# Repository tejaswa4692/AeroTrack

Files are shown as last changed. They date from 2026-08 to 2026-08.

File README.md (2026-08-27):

# Aero Track

Why should directional antennas be handicapped by the fact theyre directional, i made a rig (can be used with any directional antennas) that can be used to track a target anywhere on the earth
It will do all the math to point the antennas towards a GPS coordinate, It does have its own GPS but if you dont want to use it its totally upto you its just there for quality of life and ease of use at the field.
This project was developed to aid my Long range endurance UAV project that i also submitted for stardance and got funding from, This will help me make a groundstation that can have insane range without sacrificing directionality

Where has my love for yagi antennas brought me 😍😍✌️✌️

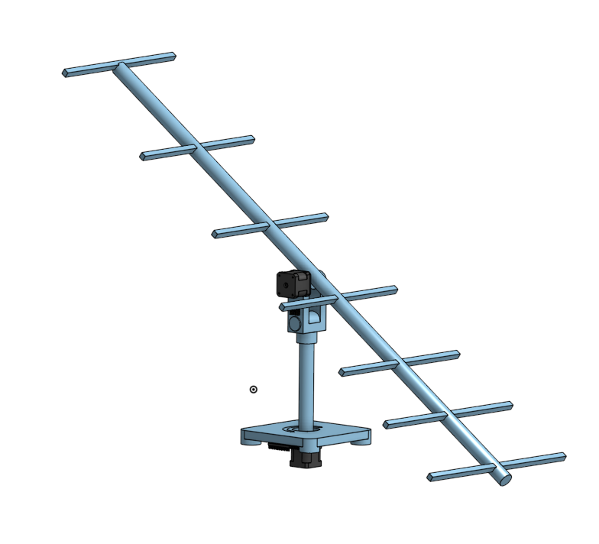
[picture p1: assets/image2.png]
Yagi Rig

___

I will be implementing full support with the Mavlink protocol so you can either directly plug ur mavlink telemetry reciever in or route the data through a laptop

## System Architecture

It uses two stepper motors with encoders for pitch and yaw 

```
base.rotation.y = atan2(local_target.x, local_target.z)
antenna.rotation.x = -atan2(local_target.y, Vector2(local_target.x, local_target.z).length()) + deg_to_rad(90)
```
(lines taken straight out of my game code btw it does work irl too)

These two formulas will be used to point the yagi towards the location i want it to point to, which will ofcourse be GPS coords in this case

I have tested this in my game which i ALSO submitted for stardance and got a superstar on 

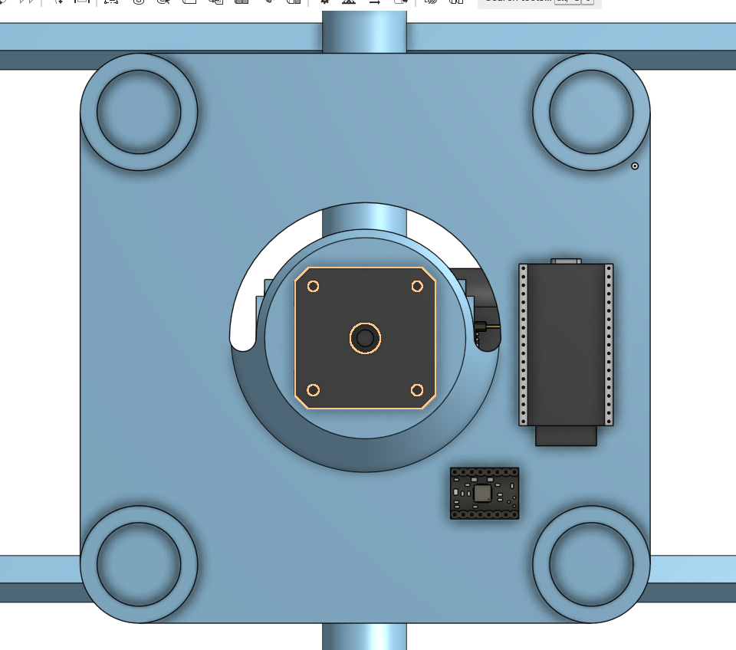
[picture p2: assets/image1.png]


### Electronics

[bom.csv](./bom.csv)

### Antenna

Yagi is a highly directional antenna which has insane range for anything thats directly infront of it, its used a LOT in TV communication and for groundstations where they know the position of the gs and they directly point it to that point
Hugely used in aerospace 

### 433 MHz Yagi

### 433 MHz Yagi — Element Dimensions

| Element | Length (mm) | Distance from Reflector (mm) |
|---|---|---|
| Reflector | 346 | 0 |
| Driven (dipole) | 329 | 138 |
| Director 1 | 311 | 276 |
| Director 2 | 308 | 486 |
| Director 3 | 305 | 767 |
| Director 4 | 303 | 1024 |
| Director 5 | 301 | 1257 |

## Wiring

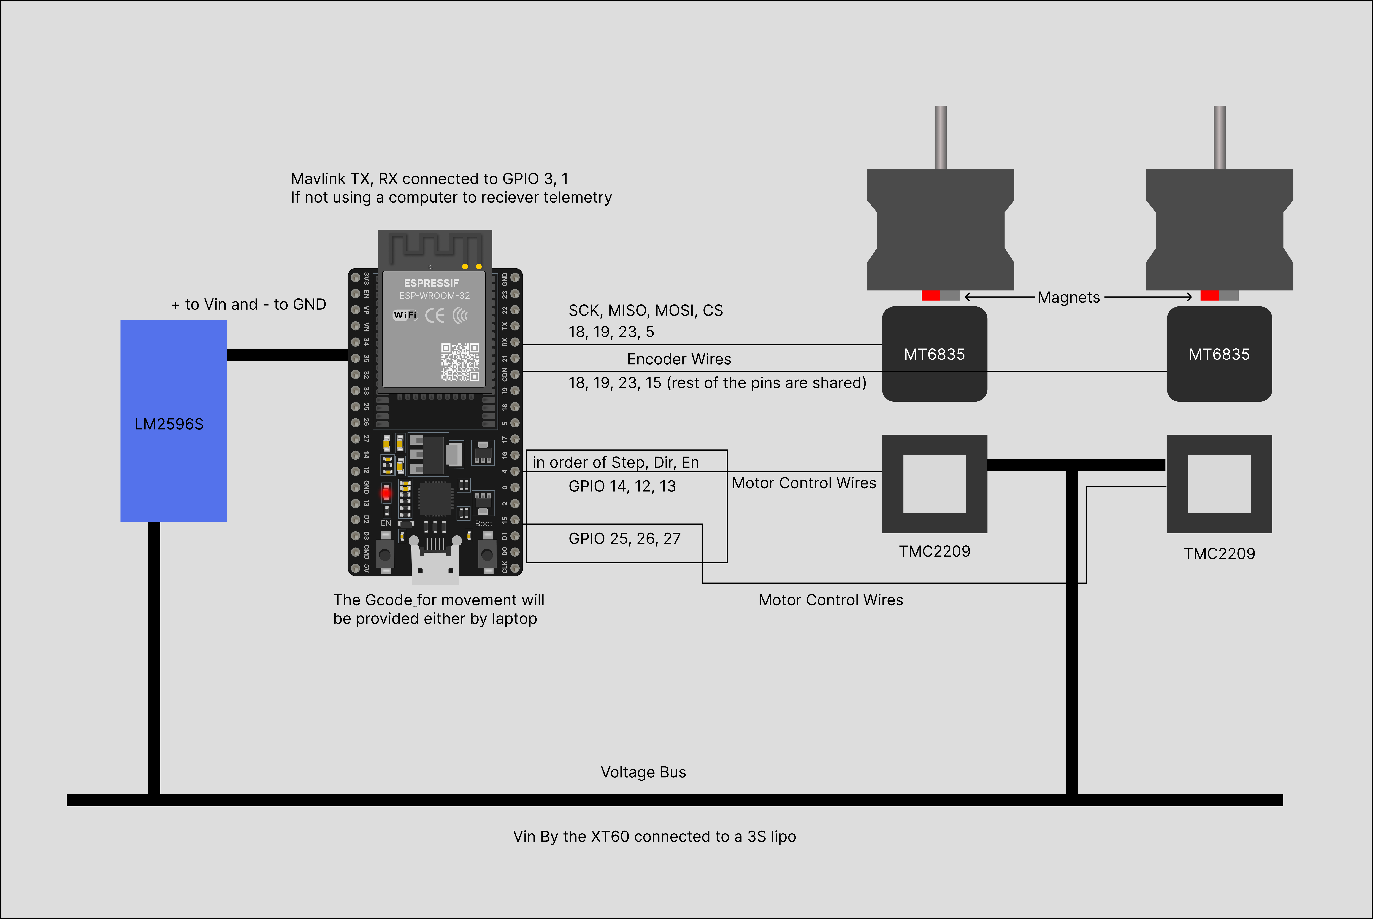
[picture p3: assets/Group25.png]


### Pin Connections

| Signal | ESP32 Pin | Connects To |
|---|---|---|
| Yaw Step | GPIO 25 | Stepper Driver 1 (STEP) |
| Yaw Dir | GPIO 26 | Stepper Driver 1 (DIR) |
| Yaw Enable | GPIO 27 | Stepper Driver 1 (EN) |
| Pitch Step | GPIO 14 | Stepper Driver 2 (STEP) |
| Pitch Dir | GPIO 12 | Stepper Driver 2 (DIR) |
| Pitch Enable | GPIO 13 | Stepper Driver 2 (EN) |
| Yaw Encoder SCK | GPIO 18 | MT6835 #1 (SPI SCK) |
| Yaw Encoder MISO | GPIO 19 | MT6835 #1 (SPI MISO) |
| Yaw Encoder MOSI | GPIO 23 | MT6835 #1 (SPI MOSI) |
| Yaw Encoder CS | GPIO 5 | MT6835 #1 (SPI CS) |
| Pitch Encoder CS | GPIO 15 | MT6835 #2 (SPI CS, shares SCK/MISO/MOSI) |
| GPS RX | GPIO 16 | GPS Module TX |
| GPS TX | GPIO 17 | GPS Module RX |
| MAVLink RX | GPIO 3 (RX0) | Telemetry Radio TX |
| MAVLink TX | GPIO 1 (TX0) | Telemetry Radio RX |
| Motor Power | VMOT | 12V Supply |
| Logic Power | 3.3V | ESP32 / Encoders |

Note: The encoder pins might be different for different encoders

## Design process
### The 433 Dipole 
Coming soon... (i dont wanna provide any false instructions)
### Firmware
Coming soon...
### Screws
insert all the provided heatset inserts before moving on to assembling the rig, the longer inserts go in the baseplate and keep in mind to leave space at top so that the screws can sit flush
the smaller 3mm inserts are tapped on the yaw arm
### Assembling the rig
1. Start by taking your boom and place the first reflector element at the end, cut the reflector to match the size given in the chart above (keep in mind it should be symmetric)
2. Place the dipole you just created 13.8cm ahead of it
3. Match the table for however many directors you want (the more the more directional it becoems)
4. Put the YagiBoomMount.step under the CG of the yagi antenna
5. Take out your 6000 bearings and slide them in the yaw arm
6. position the yagi antenna boom mounts notch inside the bearing and side your nema 17 from the side screwing it in the place
7. Slide down your 2.5cm stick under the yaw arm and superglue it in place
8. Use a lathe or drill a hole to put a 5mm shaft inside the 2.5cm shaft so that it sticks out
9. Screw your Nema17 under the baseplate before you begin the assembly
10. Slide the 6005 bearings in the base plate then follow it by adding the yawarm in, use the aluminum coupling to screw both in place
11. Rougly connect everything according to the wiring diagram to the ESP32 and mount the GPS as away from the yagi on baseplate facing up

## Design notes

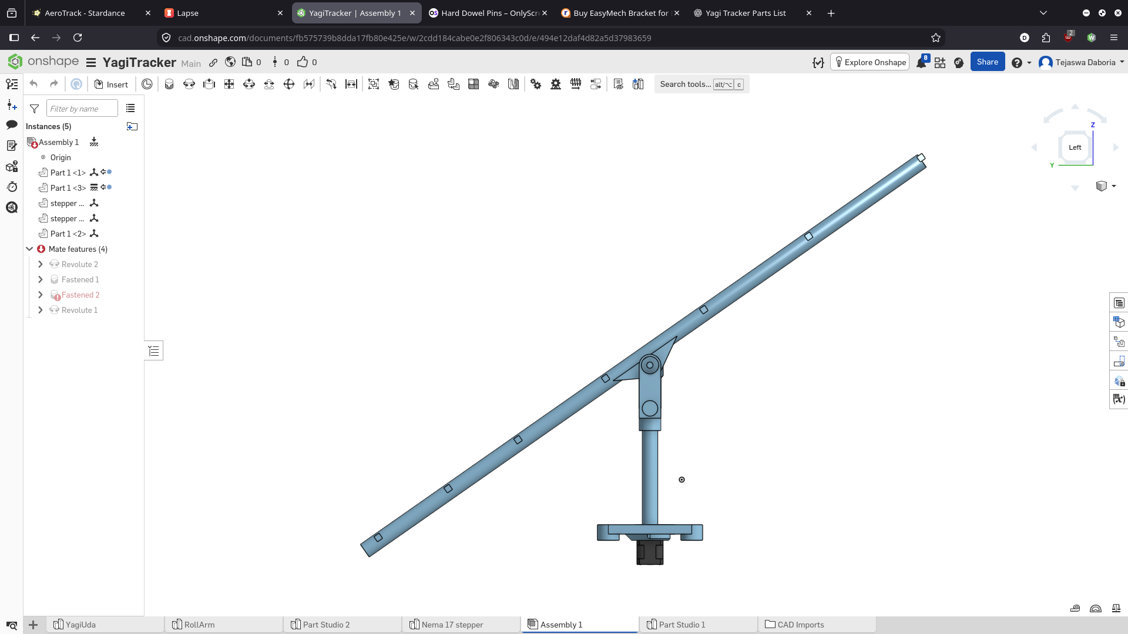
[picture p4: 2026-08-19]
assets/Screenshot_20260819_000037.png

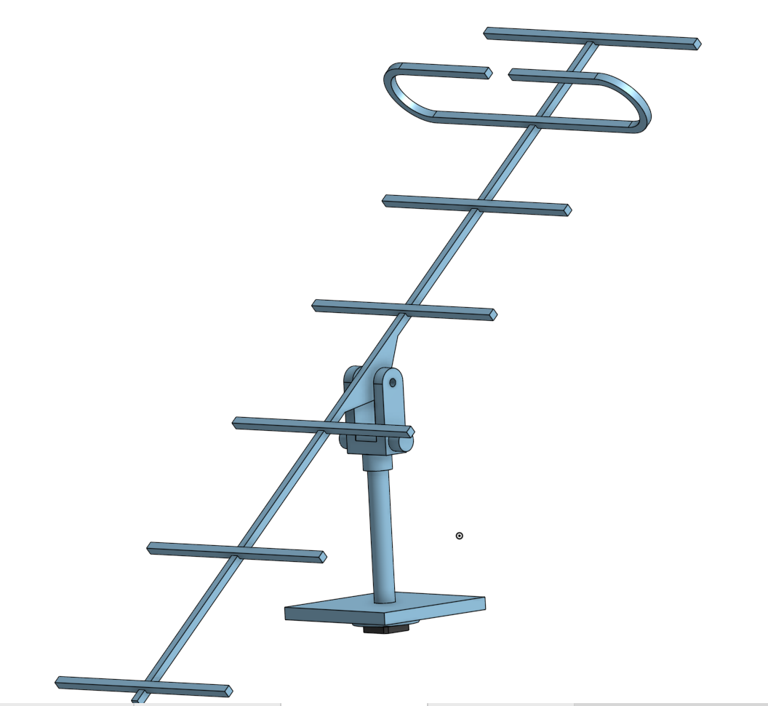
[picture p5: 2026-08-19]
assets/Screenshot_20260816_004432.png

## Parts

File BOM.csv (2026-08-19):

Item Name | Qty | Price (total) (USD) | Item link | Notes
3 ft wood dowels | 1 | $3.00 | https://www.amazon.in/Global-Hanging-Macram%C3%A9-Tapestries-Projects/dp/B0H7MLPWMG?th=1 | Wood dowles used to make the boom for yagi antenna (not using cf cuz conductive)
M3 x 12 screw | 6 | $0.21 | https://onlyscrews.in/products/hex-allen-socket-head-m3-x-12-screw-pack-of-20?variant=48590915567929 | M3 x 12 for mounting the NEMA 17 to base plate
M3 x 3mm threaded inserts | 6 | $0.28 | https://onlyscrews.in/products/m3-x-3mm-brass-threaded-inserts?variant=49729062273337 | For the rotating arm
M3 x 8 threaded inserts | 6 | $0.19 | https://onlyscrews.in/products/m3-x-8mm-brass-threaded-inserts?variant=49423134327097 | For the base plate
6000Z bearing | 2 | $0.38 | https://onlyscrews.in/products/6000-zz-deep-groove-ball-bearing-10x26x8?variant=50974148362553 | THis bearing will be for the arm (yaw)
6005Z bearing | 2 | $0.90 | https://onlyscrews.in/products/6005-zz-deep-groove-ball-bearing-25x47x12?variant=50975888376121 | This bearing will be for the base plate (pitch)
M3 x 6 screws | 6 | $0.11 | https://onlyscrews.in/products/m3-x-6mm-hex-allen-socket-head-high-tensile12-9-black-oxide-screw-dia-3mm-length-6mm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 | Mounting screws for NEMA 17
ESP32-32D | 1 | $8.55 | https://robu.in/product/smartelex-esp-wroom-32-wifi-bluetooth-networking-development-board-1-pcs/ | ESP with enough pins to power the project
TMC2209 | 2 | $11.88 | https://robu.in/product/tmc2209-stepper-motor-driver/ | Stepper motor driver w high accuracy
MT6835 | 2 | $15.22 | https://robu.in/product/mt6835-magnetic-encoder-module-pwm-spi-brushless-motor-21bit-encoder-with-magnet-to-replace-as5048-ab-16384/ | Best quality stepper encoder to find shaft angle
LM2596S | 2 | $0.92 | https://robu.in/product/lm2596s-dc-dc-buck-converter-power-supply/ | Buck convertor to power the ESP (might need to use smt else but this is js for the prototype)
NEO-6M GPS | 1 | $3.00 | https://robu.in/product/neo-6m-gps-module-with-eprom-normal-quality/ | Cheap GPS works just fine to find the position of antenna
NEMA17 4.2 kg | 2 | $14.62 | https://robu.in/product/nema17-40mm-1-2a-unipolar-stepper-motor-w-1m-cable/ | 4.2Kg Nema17 has more than enoguh power to move the entire earth on its own
Aluminum NEMA17 Shaft Coupling | 1 | $1.19 | https://robu.in/product/easymech-aluminium-nema17-shaft-coupling-5mm-x-8mm/ | This holds the wood dowel of the arm
NEMA 17 Stepper Motor Bend Sturdy Mount | 1 | $2.11 | https://robu.in/product/easymech-bracket-for-nema-17-stepper-motor/ | If incase the arm mounting bracket is too flimsy for the nema 17 chonky boy i will use this instead
XT60 | 1 | $0.31 | https://robu.in/product/xt60h-connector-with-housing-male/ | To power the project im using a 3s lipo
Wire | 1 | $0.20 | https://robu.in/product/high-quality-ultra-flexible-22awg-silicone-wire-1000m-black/ | Wire to spread the electricity
F-F jumpers | 3 | $1.38 | https://robu.in/product/male-to-female-jumper-wires-40pcs-20cm/ | For the initial prototyping stage i will be soldering them manually later
Tire spokes | 20 | $7.00 | Local Shop | For the yagi director
Single core copper wire | 2 | $0.35 | https://robu.in/product/26awg-single-core-teflon-wire-red/ | Driven element single cored copper wire enough for multiple types of antennas
RP SMA 1m Male-Male Cable | 1 | $7.11 | https://www.amazon.in/gp/product/B0GZLPBMM2?smid=AID930I70H9OP&th=1 | 1 m long RP SMA male - male coax to wire the yagi
RP sma 5 cm female cable | 1 | $0.82 | https://robu.in/product/5cm-ipex-1-to-rp-sma-female-connector-cable-11mm-rg1-13/ | a small female rp sma connector so i dont ruin the coax cable when making the yagi
OnlyScrews delivery charge | 1 | $1.10 | OnlyScrews delivery charge | OnlyScrews delivery charge
Total Price (USD):
 |  | $80.83

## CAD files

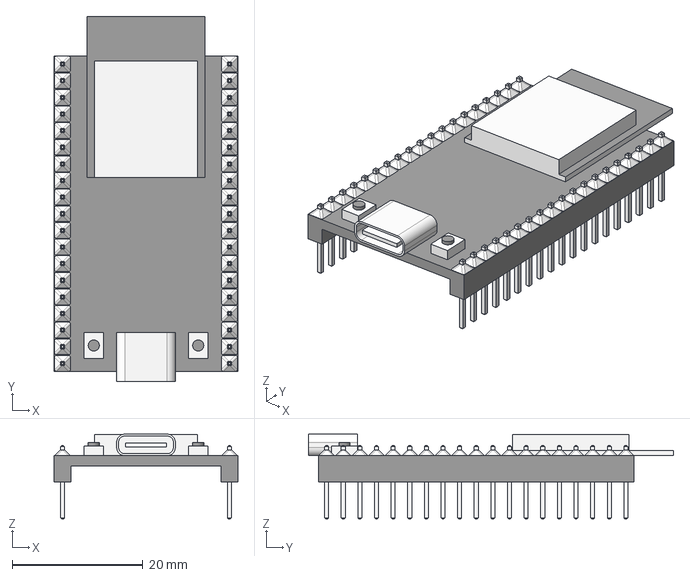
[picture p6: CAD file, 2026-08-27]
cad/ESP32-32D - Main Board.step
28.0 x 55.8 x 13.0 mm

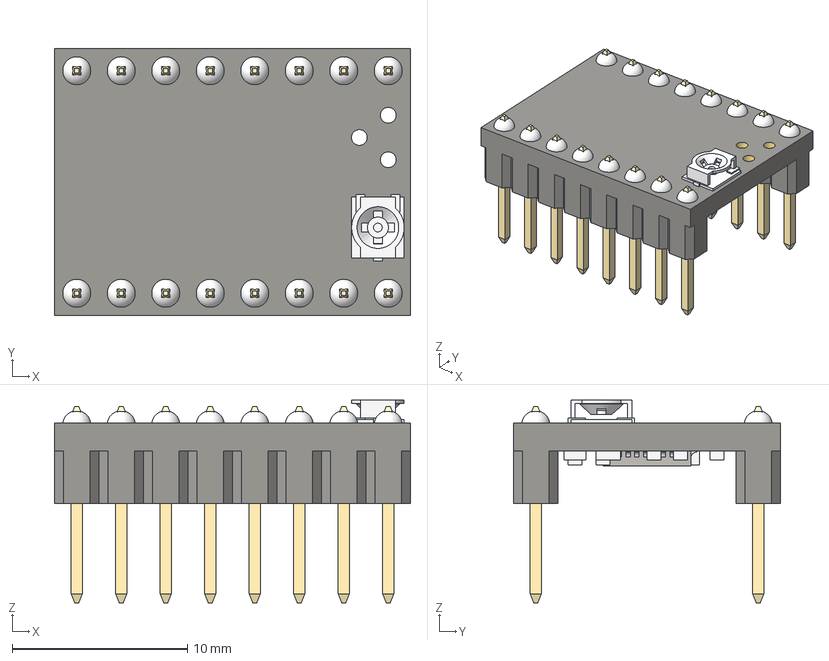
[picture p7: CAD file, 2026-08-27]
cad/TMC2209 - TMC2209.step
20.3 x 15.2 x 11.6 mm

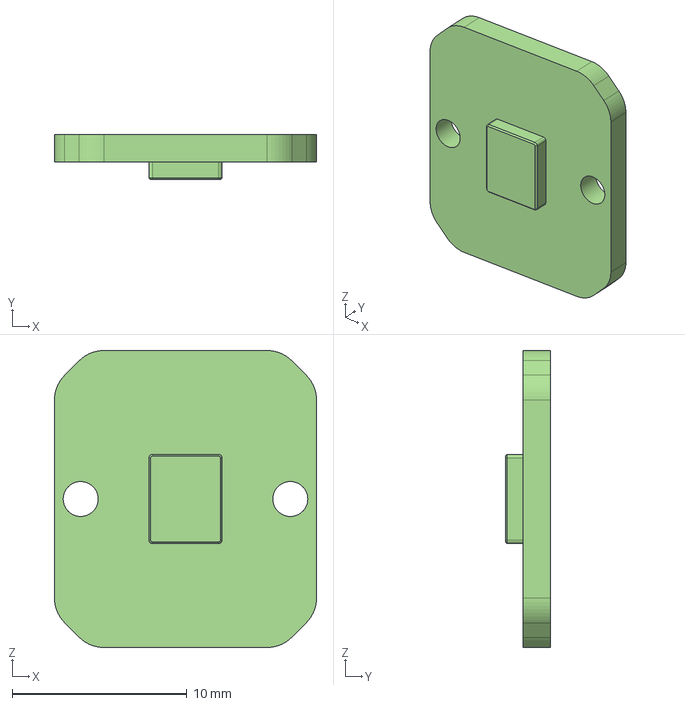
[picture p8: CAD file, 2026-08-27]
cad/Parts - MT6835.step
15.0 x 2.60 x 17.0 mm

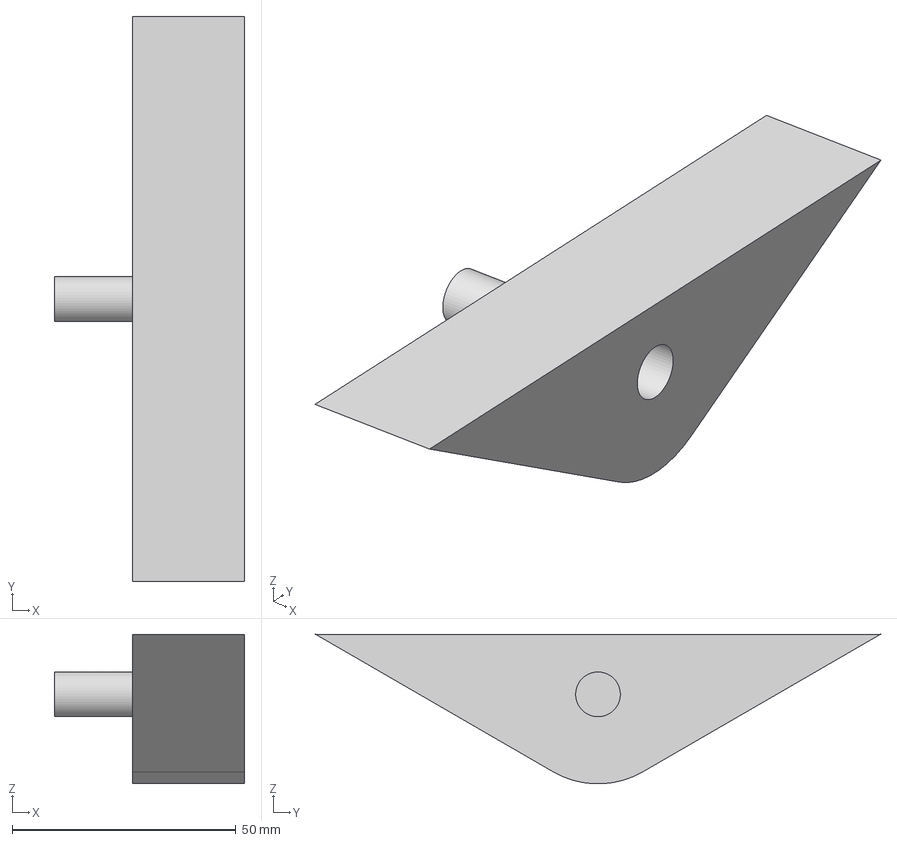
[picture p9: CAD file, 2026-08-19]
cad/YagiBoomMount.step
42.5 x 126.2 x 33.4 mm

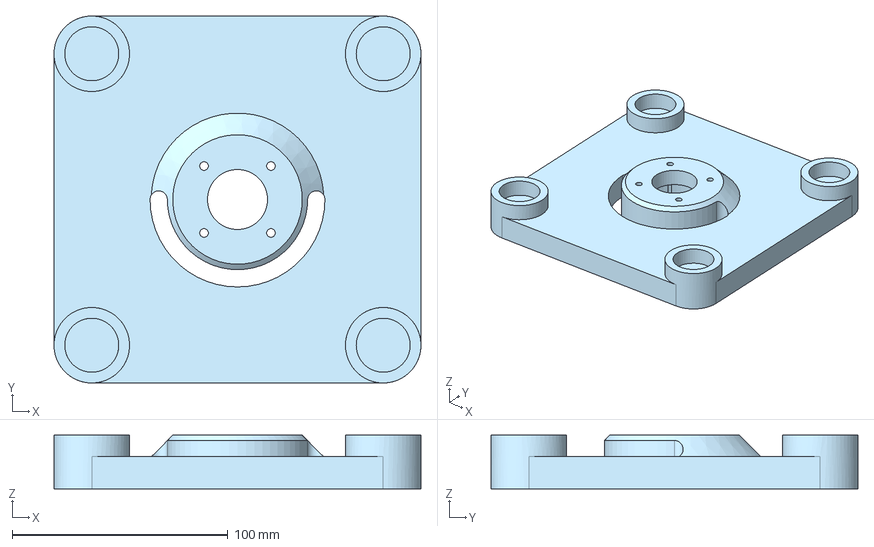
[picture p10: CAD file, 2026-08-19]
cad/BasePlate.step
170.0 x 170.0 x 25.0 mm

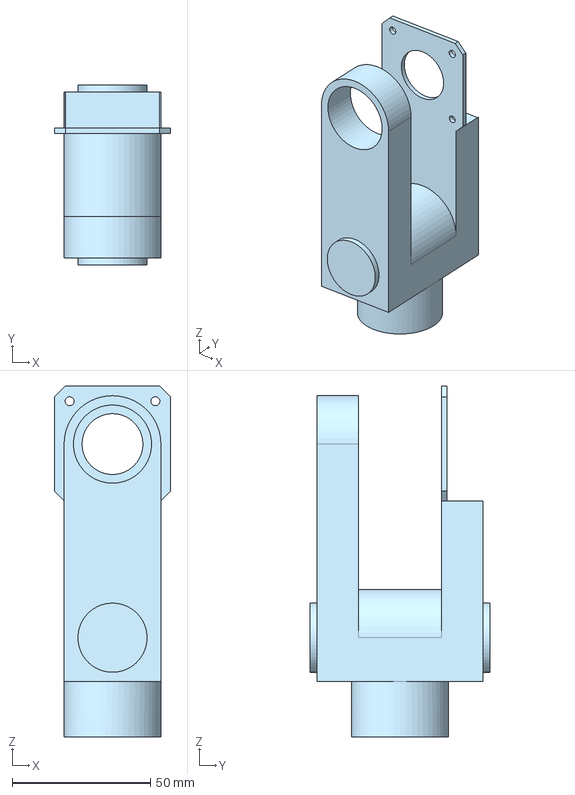
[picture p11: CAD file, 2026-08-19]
cad/YawArm.step
42.0 x 65.0 x 126.9 mm

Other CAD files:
cad/BasePlate.3mf

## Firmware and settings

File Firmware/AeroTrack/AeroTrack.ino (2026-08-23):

//MAKE SURE TO SELECT ESP32 DEV BOARD TO COMPILE MR REVIWER

#define STEP_AZ   25
#define DIR_AZ    26
#define EN_AZ     27

#define STEP_EL   32
#define DIR_EL    33
#define EN_EL     14

#define CS_ENC_AZ 5
#define CS_ENC_EL 4

#define TMC_SERIAL   Serial2
#define TMC_RX_PIN   16
#define TMC_TX_PIN   17
#define R_SENSE      0.11f   // verify against your specific TMC2209 breakout

#include <TMCStepper.h>
#include <SPI.h>
#include "MT6835.h"

TMC2209Stepper driverAz(&TMC_SERIAL, R_SENSE, 0);
TMC2209Stepper driverEl(&TMC_SERIAL, R_SENSE, 1);

MT6835 encAz(CS_ENC_AZ, SPI);
MT6835 encEl(CS_ENC_EL, SPI);

// ---- Tuning parameters ----
const float DEADBAND_DEG      = 0.15f;   // stop stepping once within this error
const float EL_MIN_DEG        = 0.0f;    // mechanical safety limits for elevation
const float EL_MAX_DEG        = 90.0f;
const uint32_t MIN_STEP_US    = 400;     // fastest step pulse interval (large error)
const uint32_t MAX_STEP_US    = 4000;    // slowest step pulse interval (near target)
const float FULL_SPEED_ERR_DEG = 20.0f;  // error magnitude at which we hit MIN_STEP_US

// ---- Axis state ----
struct Axis {
    uint8_t stepPin, dirPin;
    float targetDeg = 0.0f;
    float currentDeg = 0.0f;
    bool haveReading = false;
    uint32_t lastStepMicros = 0;
};

Axis axisAz = {STEP_AZ, DIR_AZ};
Axis axisEl = {STEP_EL, DIR_EL};

// Shortest signed angular distance from a to b, result in (-180, 180]
float angleDiff(float a, float b) {
    float d = fmodf(b - a + 540.0f, 360.0f) - 180.0f;
    return d;
}

void configureDriver(TMC2209Stepper &drv) {
    drv.begin();
    drv.toff(4);
    drv.rms_current(800);       // mA - tune to your motor's rated current
    drv.microsteps(16);
    drv.pwm_autoscale(true);
    drv.en_spreadCycle(false);  // StealthChop for quiet tracking motion
}

void serviceAxis(Axis &ax, float measuredDeg, bool clampEl) {
    ax.currentDeg = measuredDeg;
    ax.haveReading = true;

    float target = ax.targetDeg;
    if (clampEl) target = constrain(target, EL_MIN_DEG, EL_MAX_DEG);

    float err = angleDiff(ax.currentDeg, target);

    // Safety: never drive elevation further past its mechanical limit
    if (clampEl) {
        if (ax.currentDeg >= EL_MAX_DEG && err > 0) err = 0;
        if (ax.currentDeg <= EL_MIN_DEG && err < 0) err = 0;
    }

    if (fabsf(err) < DEADBAND_DEG) return; // within deadband, hold position

    digitalWrite(ax.dirPin, err > 0 ? HIGH : LOW);

    // Scale step rate with error magnitude - faster when far, slower near target
    float mag = fminf(fabsf(err), FULL_SPEED_ERR_DEG) / FULL_SPEED_ERR_DEG;
    uint32_t interval = MAX_STEP_US - (uint32_t)(mag * (MAX_STEP_US - MIN_STEP_US));

    uint32_t now = micros();
    if (now - ax.lastStepMicros >= interval) {
        digitalWrite(ax.stepPin, HIGH);
        delayMicroseconds(3); // TMC2209 min step pulse width
        digitalWrite(ax.stepPin, LOW);
        ax.lastStepMicros = now;
    }
}

// ---- Serial command parsing ----
String serialBuf;

void handleCommand(const String &line) {
    int azIdx = line.indexOf("AZ:");
    int elIdx = line.indexOf("EL:");

    if (azIdx >= 0) {
        axisAz.targetDeg = line.substring(azIdx + 3).toFloat();
    }
    if (elIdx >= 0) {
        axisEl.targetDeg = constrain(line.substring(elIdx + 3).toFloat(), EL_MIN_DEG, EL_MAX_DEG);
    }

    Serial.printf("Target -> AZ:%.2f EL:%.2f\n", axisAz.targetDeg, axisEl.targetDeg);
}

void setup() {
    Serial.begin(115200);
    TMC_SERIAL.begin(115200, SERIAL_8N1, TMC_RX_PIN, TMC_TX_PIN);

    pinMode(EN_AZ, OUTPUT);
    pinMode(EN_EL, OUTPUT);
    digitalWrite(EN_AZ, LOW); // TMC2209 EN is active-low
    digitalWrite(EN_EL, LOW);

    pinMode(STEP_AZ, OUTPUT);
    pinMode(DIR_AZ, OUTPUT);
    pinMode(STEP_EL, OUTPUT);
    pinMode(DIR_EL, OUTPUT);

    configureDriver(driverAz);
    configureDriver(driverEl);

    SPI.begin(); // default VSPI pins: SCK=18, MOSI=23, MISO=19
    encAz.begin();
    encEl.begin();

    Serial.println("AeroTrack ready. Send commands like: AZ:135.0 EL:42.5");
}

uint32_t lastStatusPrint = 0;

void loop() {
    // Read serial commands
    while (Serial.available()) {
        char c = Serial.read();
        if (c == '\n') {
            handleCommand(serialBuf);
            serialBuf = "";
        } else if (c != '\r') {
            serialBuf += c;
        }
    }

    // Read encoders
    float azDeg, elDeg;
    uint8_t azStatus, elStatus;
    bool azOk = encAz.readAngle(azDeg, azStatus);
    bool elOk = encEl.readAngle(elDeg, elStatus);

    if (azOk) serviceAxis(axisAz, azDeg, false);
    if (elOk) serviceAxis(axisEl, elDeg, true);

    // Periodic status print for tuning/debugging
    if (millis() - lastStatusPrint > 500) {
        lastStatusPrint = millis();
        Serial.printf("AZ: cur=%.2f tgt=%.2f (crc=%s)  EL: cur=%.2f tgt=%.2f (crc=%s)\n",
            axisAz.currentDeg, axisAz.targetDeg, azOk ? "ok" : "FAIL",
            axisEl.currentDeg, axisEl.targetDeg, elOk ? "ok" : "FAIL");
    }
}

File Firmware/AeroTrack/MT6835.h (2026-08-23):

// MT6835.h - Minimal driver for MagnTek MT6835 21-bit SPI magnetic encoder
// Protocol reference: MT6835 Datasheet Rev.1.3 (2022.12), Section 7.6
//
// SPI mode: MODE3 (CPOL=1, CPHA=1)
// Burst angle read command: 0b1010, register address 0x003
// Frame: [C3 C2 C1 C0 A11..A0] (16 bits header) then 4 data bytes:
//   0x003 = ANGLE[20:13]
//   0x004 = ANGLE[12:5]
//   0x005 = ANGLE[4:0] | STATUS[2:0]
//   0x006 = CRC[7:0]  (CRC-8, poly x^8+x^2+x+1 = 0x07, over the 24 angle+status bits)
//
// NOTE on CRC init value: the datasheet specifies the polynomial but not the
// shift-register initial value explicitly. This implementation assumes init=0x00,
// which is the common default for this polynomial family. If crcOk is false on
// every read despite a stable, correctly-wired sensor, that init assumption is
// the first thing to re-check against a logic analyzer capture.

#pragma once
#include <SPI.h>

class MT6835 {
public:
    MT6835(uint8_t csPin, SPIClass &spiBus, uint32_t spiHz = 1000000)
        : _cs(csPin), _spi(spiBus), _hz(spiHz) {}

    void begin() {
        pinMode(_cs, OUTPUT);
        digitalWrite(_cs, HIGH);
    }

    // Reads the current angle. Returns true if the CRC check passed.
    // angleDeg: 0.0 - 360.0 (only valid if this call returns true)
    // status: STATUS[2:0] bits - bit0 overspeed, bit1 weak field, bit2 undervoltage
    bool readAngle(float &angleDeg, uint8_t &status) {
        uint8_t buf[4]; // will hold data from 0x003, 0x004, 0x005, 0x006

        SPISettings settings(_hz, MSBFIRST, SPI_MODE3);
        _spi.beginTransaction(settings);
        digitalWrite(_cs, LOW);

        // Header: command=1010, address=0x003 -> 16 bits total
        // byte0 = C3 C2 C1 C0 A11 A10 A9 A8 = 1010 0000 = 0xA0
        // byte1 = A7 A6 A5 A4 A3 A2 A1 A0   = 0000 0011 = 0x03
        _spi.transfer(0xA0);
        _spi.transfer(0x03);

        // Burst-clock out the 4 data bytes (0x003..0x006)
        for (int i = 0; i < 4; i++) {
            buf[i] = _spi.transfer(0x00);
        }

        digitalWrite(_cs, HIGH);
        _spi.endTransaction();

        uint8_t angleHi   = buf[0]; // ANGLE[20:13]
        uint8_t angleMid  = buf[1]; // ANGLE[12:5]
        uint8_t angleLoSt = buf[2]; // ANGLE[4:0] | STATUS[2:0]
        uint8_t crcRx     = buf[3];

        status = angleLoSt & 0x07;

        uint32_t angle21 = ((uint32_t)angleHi << 13) |
                            ((uint32_t)angleMid << 5) |
                            ((uint32_t)(angleLoSt >> 3) & 0x1F);

        angleDeg = (angle21 * 360.0f) / 2097152.0f; // 2^21

        uint8_t crcCalc = crc8(angleHi, angleMid, angleLoSt);
        return crcCalc == crcRx;
    }

private:
    uint8_t _cs;
    SPIClass &_spi;
    uint32_t _hz;

    // CRC-8, polynomial x^8+x^2+x+1 (0x07), MSB-first, init = 0x00
    static uint8_t crc8(uint8_t b0, uint8_t b1, uint8_t b2) {
        uint8_t data[3] = {b0, b1, b2};
        uint8_t crc = 0x00;
        for (int i = 0; i < 3; i++) {
            crc ^= data[i];
            for (int bit = 0; bit < 8; bit++) {
                if (crc & 0x80) crc = (crc << 1) ^ 0x07;
                else crc <<= 1;
            }
        }
        return crc;
    }
};

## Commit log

2026-08-19 here yall go
    [BasePlate.step, Bom.csv, YagiBoomMount.step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]
2026-08-19 Add 433 MHz Yagi antenna details to README
    Added a section on 433 MHz Yagi antenna specifications with a table.
2026-08-19 updated bom
    [BOM.csv]
2026-08-20 updated image
    [BasePlate.3mf]
2026-08-27 added the step files for mcu doesnt need to be 3d pritned
    [ESP32-32D - Main Board.step, Parts - MT6835.step, TMC2209 - TMC2209.step]
